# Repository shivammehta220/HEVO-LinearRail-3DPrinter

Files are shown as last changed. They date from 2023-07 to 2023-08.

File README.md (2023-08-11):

# HEVO 3D-Printer with Linear Rails
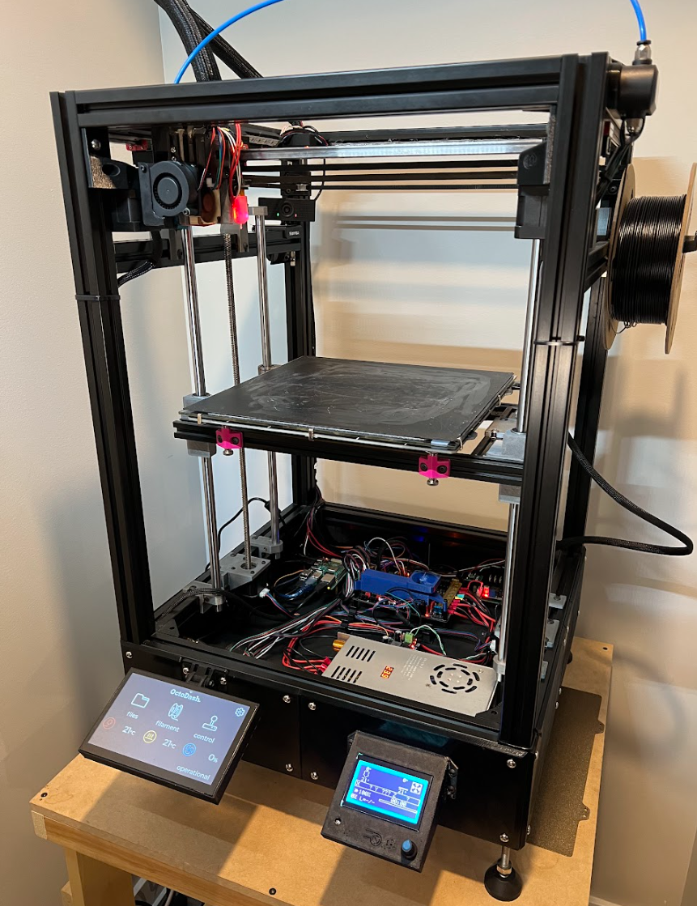
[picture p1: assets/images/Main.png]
Main

## About This Project
This project is an adaptation and build of the HyperCube Evolution (HEVO) project by SCOTT_3D. The objective was to construct a modified version of the HEVO printer with an increased height to achieve a larger build volume in the Z-axis. Additionally, the project aimed to incorporate a compartment for electronics and upgrade the original linear rods to MGN Linear rails.

The repository contains CAD files, documentation, STLs, BOMs, and Marlin files related to this project.

### Quick Links
1. [Electronics](/Electronics/README.md)
2. [Frame](/Design/README.md)
3. [Linear Rail Design](/Design/README.md)
4. [Octoprint](/Octoprint/README.md)

## [Electronics](/Electronics/README.md)
The electronics used in this project differ from the original design. They are all securely mounted using standoffs in the lower compartment of the frame. For the mainboard, the BIGTREETECH SKR PRO V1.1 Control Board with TMC2209 drivers was selected due to its ample room for expandability and future upgrades. The board is running Marlin 2.0, and the customized fork can be [found here](https://github.com/shivammehta220/Marlin/tree/HEVO).

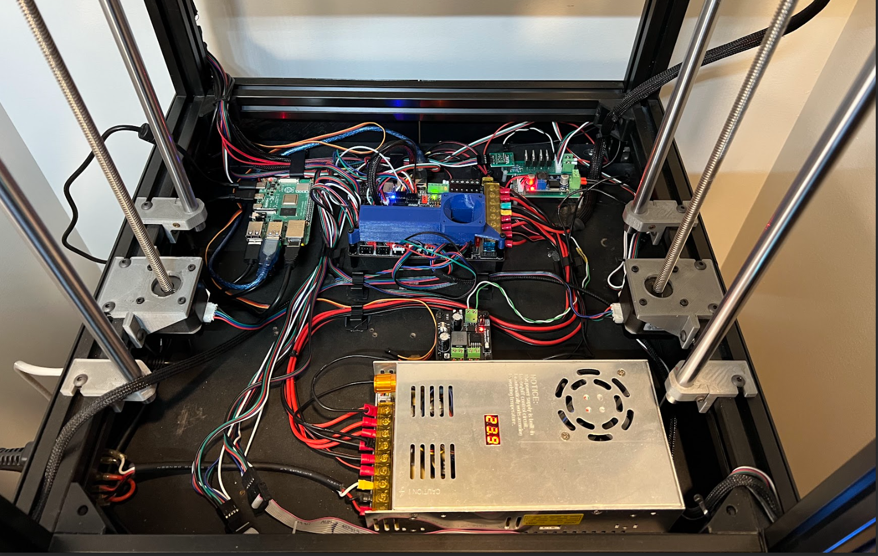
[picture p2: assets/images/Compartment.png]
Compartment


## [Frame](/Design/README.md)
The printer's frame was purchased and laser-cut from MISUMI, with overall dimensions of 440x450x700 mm. The frame is designed to provide stability and support for the printer components. The original build volume of SCOTT_3D's design is 300x300x300 mm, but it has been upgraded to 300x300x450 mm, with an additional 200 mm of extrusion in the lower section for housing the electronics. All printed components are made using PETG filament. The STLs and CAD files for all the components used, as well as the Hypercube configurator for the build layout, can be found in the Design folder of this repository.

## [Linear Rail Design](/Design/README.md)
To enhance the printer's performance, the linear rod rails used in the original design were replaced with linear rails. This upgrade was implemented using a project found at [https://www.thingiverse.com/thing:2839395]. Additionally, a custom bracket was designed to mount the Trianglelab BMG extruder + V6 Hotend. The CAD files for these upgrades are available in the Design folder of this repository.

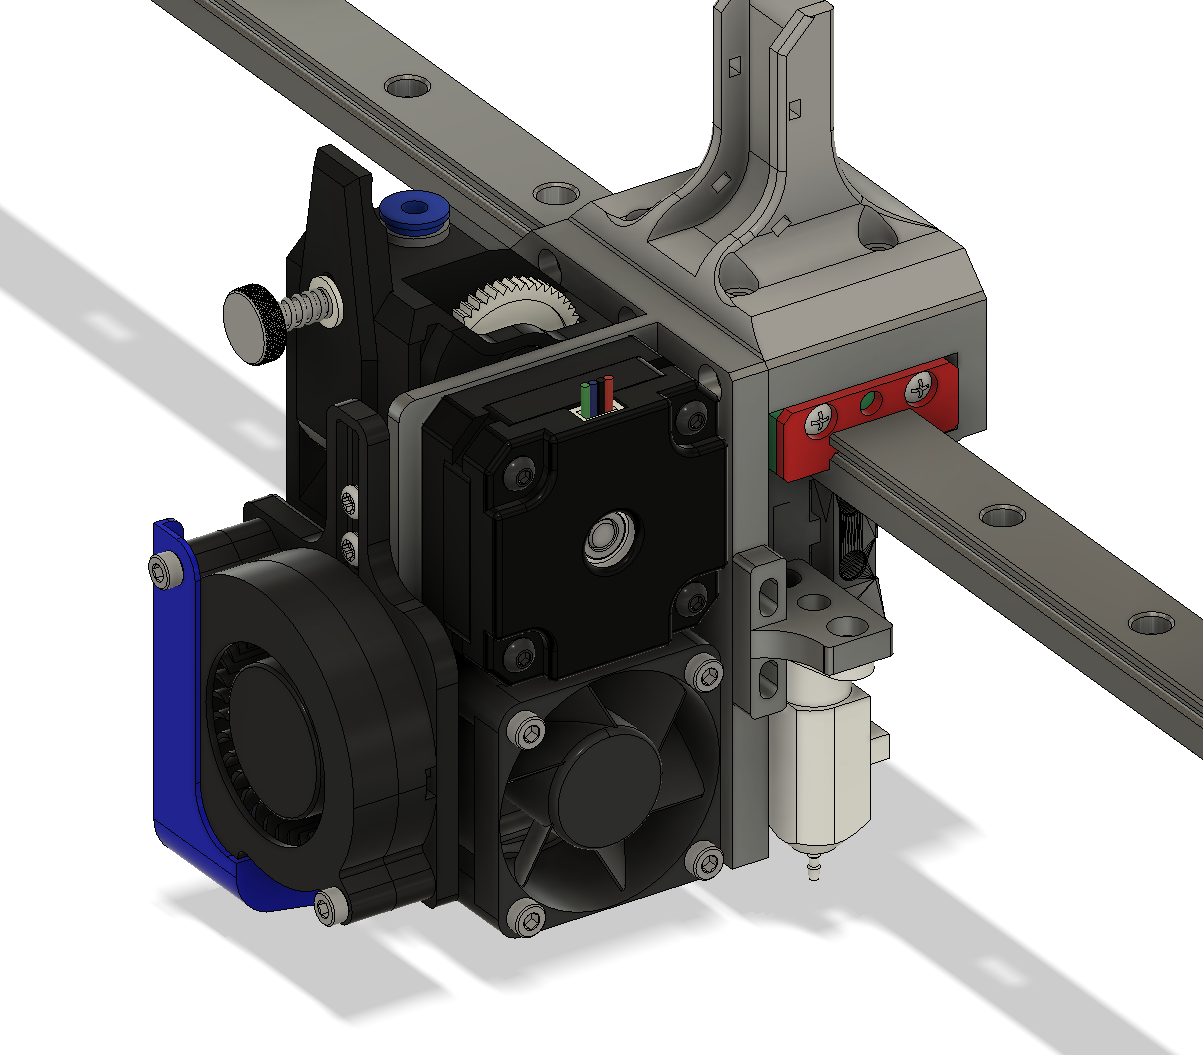
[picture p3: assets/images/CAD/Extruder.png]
Extruder


## [Octoprint](/Octoprint/README.md)
OctoPrint, a web interface for controlling and monitoring the printer remotely, is hosted on a Raspberry Pi 4. To complement the web interface, a 7-inch touch screen LCD is paired with the Pi to access the files. All plugins and settings for OctoPrint can be found in the OctoPrint folder of this repository, along with their corresponding links and documentations.

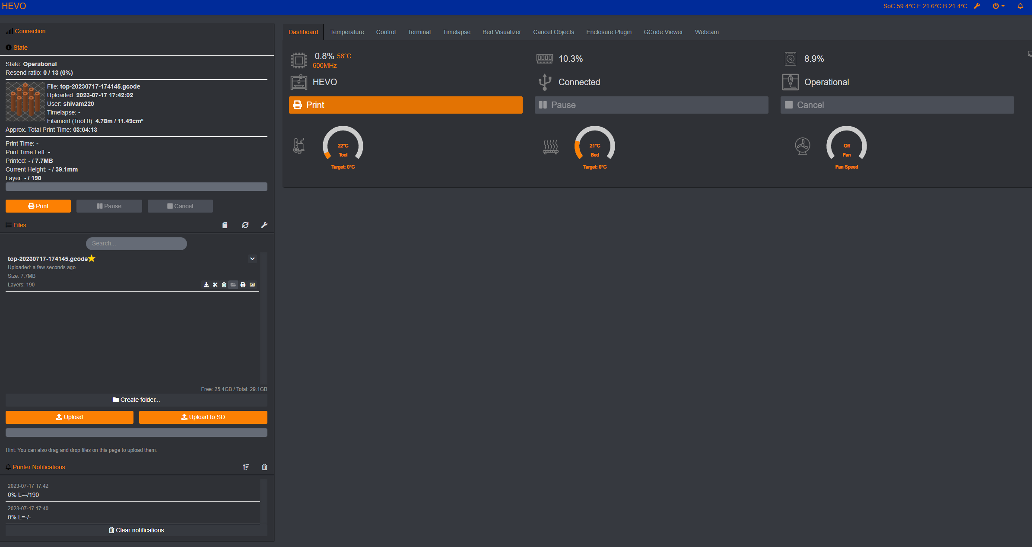
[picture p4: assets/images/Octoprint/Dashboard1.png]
Dashboard1


## Acknowledgements
This project is based on and adapted from the HyperCube Evolution project by SCOTT_3D. I would like to express my gratitude to SCOTT_3D for providing the inspiration and foundation for this project, as well as all the remixes that contributed to making it possible.

## License
The design files and documentation in this repository are licensed under MIT LICENSE. Please review the license file for more information.

Feel free to explore the repository and utilize the resources provided to build and customize your own version of the printer. If you have any questions or suggestions, please don't hesitate to reach out. Happy printing!

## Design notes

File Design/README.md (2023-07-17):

# Design
Before building the HEVO, a CAD model of the printer was created using Autodesk Fusion 360. This step was instrumental in ensuring accurate frame dimensions and assisting in the design of upgrades.

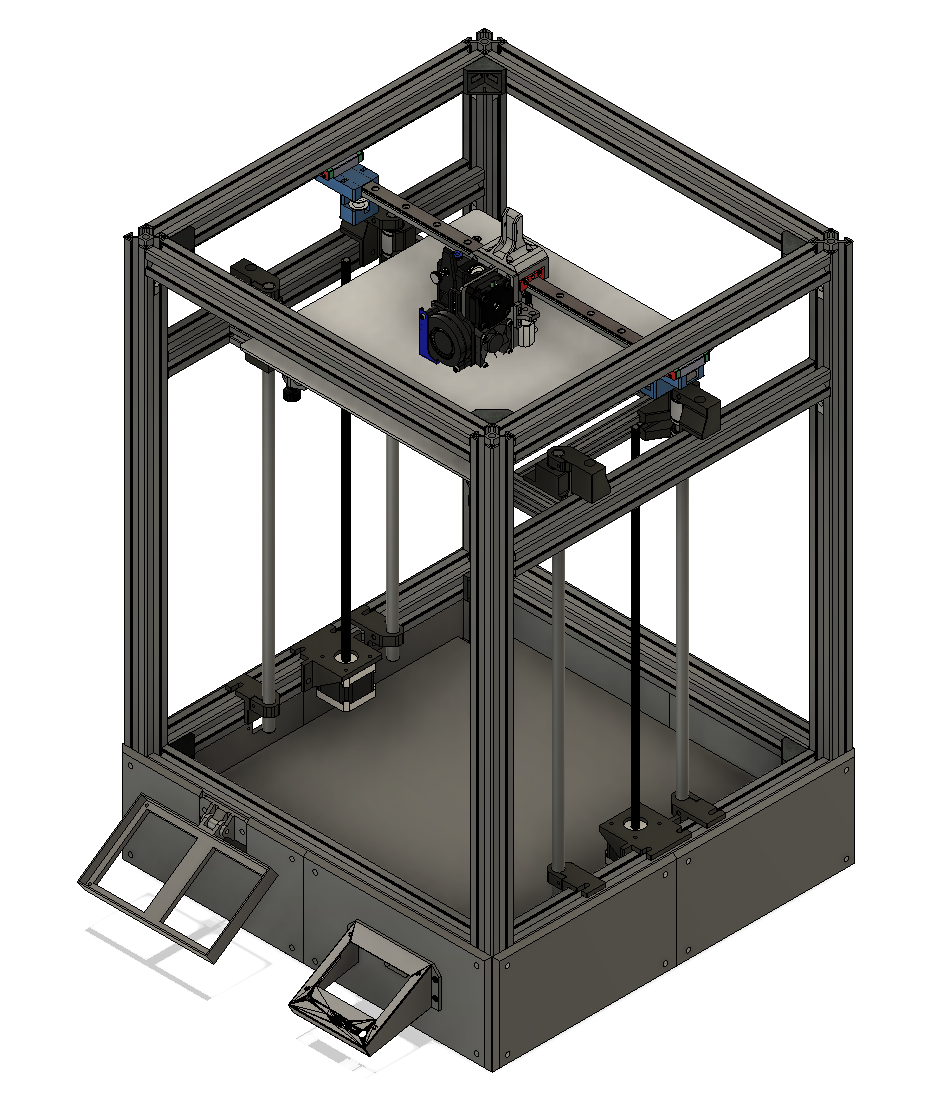
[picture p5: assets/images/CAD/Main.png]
CAD Main


## Extrusion
Instead of manually cutting the 3030 extrusion, which can introduce dimensional errors and lead to an uneven frame, I opted to have the individual extrusions laser-cut by MISUMI. The cost was reasonable, and the peace of mind in achieving a squared frame made it well worth it. The hardware for the frame and components were sourced from various online retailers and are all listed in the Bill of Materials (BOM) sheet.

| Extrusion (mm) | Type | Quantity |
| --- | --- | --- |
| 420 | 3030 Black Alu profiles | 6 |
| 410 | 3030 Black Alu profiles | 8 |
| 700 | 3030 Black Alu profiles | 4 |
| 415 | 2020 Black Alu profiles | 2 |
| 235 | 2020 Black Alu profiles | 2 |

## Linear Rail
To enhance the printer's performance, the original linear rod rails were upgraded to linear rails. This improvement was achieved by utilizing a project found at [https://www.thingiverse.com/thing:2839395]. Additionally, a custom bracket was designed to mount the Trianglelab BMG extruder + V6 Hotend.

Extruder

## CAD and STL
The repository provides the complete assembly CAD, including the frame design and any custom-designed components. Additionally, STL files for all the printed parts are included and organized in folders. Various components and features in the design were sourced from online platforms such as Thingiverse.

### 3030 LED by alexkainzinger 
>[Thingiverse Link](https://www.thingiverse.com/thing:3542857)

### Spool Holder by kuhnikuehnast 
> [Thingiverse Link](https://www.thingiverse.com/thing:3155344)

### Runout Sensor 3030 Mount by @scramsby_94717 
> [Printables Link](https://www.printables.com/model/110622-bigtreetech-smart-filament-sensor-3030-mount)

### RepRap Display by jmdunlap01
> [Thingiverse Link](https://www.thingiverse.com/thing:4787976)

### Bed Bracket by EagleB3
> [Thingiverse Link](https://www.thingiverse.com/thing:3656358)

### 3030 Cable Ties by bkahan
> [Thingiverse Link](https://www.thingiverse.com/thing:4384503)

### BIGTREETECH SKR PRO Cooling Tunnel by raabi91 
> [Thingiverse Link](https://www.thingiverse.com/thing:3747006)

These resources were instrumental in enhancing the functionality and usability of the HEVO printer design.

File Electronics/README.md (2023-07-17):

# Electronics
In this section, you can find the manuals and repositories related to the electronics used in the project. The complete list of electronics can be found in the BOM Excel sheet, but here are some of the main components:

| Component |
| ------------- |
| BIGTREETECH SKR PRO V1.1 Control Board  | 
| Trianglelab BMG extruder  | 
| Trianglelab V6 Hotend  | 
| 300x300 Magnetic Heated Bed  | 
| BLTOUCH Auto Bed Leveling Sensor | 
| 2 × NEMA17 0.9 Degree Stepper Motor - 40mm  | 
| BIGTREETECH Smart Filament Sensor Break Detection Module BTT SFS V1.0 Monitor | 
| 2 × NEMA17 Stepper Motor With Attached Lead Screw- 40mm  | 

## Electronics Compartment
The electronics compartment houses all the printer's electronics. It is enclosed with printed side panels and features cutouts for the power outlet, Ethernet, and both the RepRap display and the display for OctoPrint.

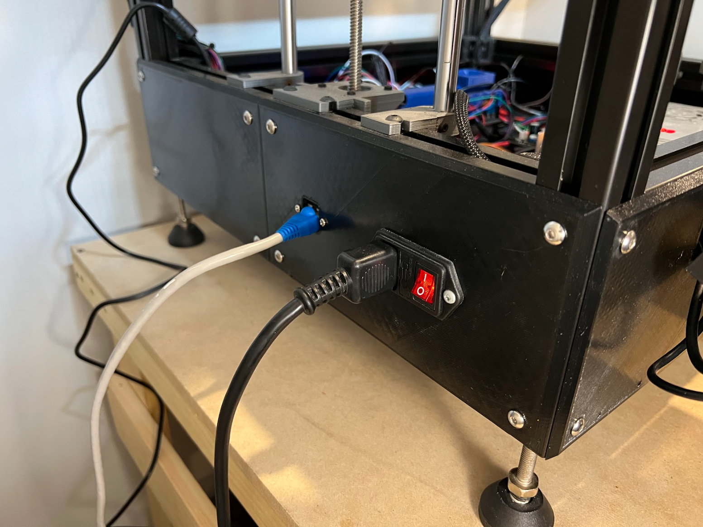
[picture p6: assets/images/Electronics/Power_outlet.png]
Power_outlet

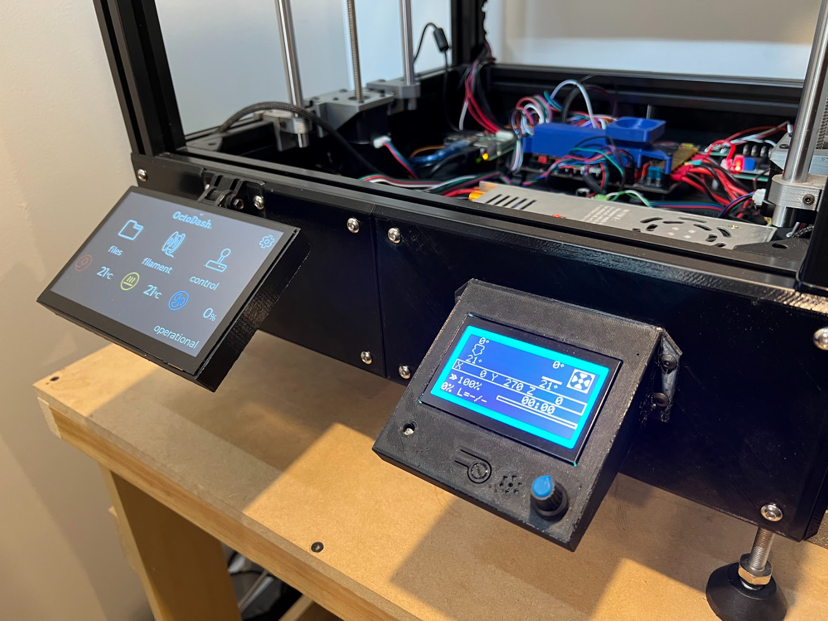
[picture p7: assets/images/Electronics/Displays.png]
Displays


## RGBW LED, 12V Regulator and Controller
To provide visualization of the print bed during prints and indicate the print status, RGBW LEDs are mounted on the 3030 extrusion frame. The LED strips themselves cannot be controlled by the SKR PRO V1.1 Control Board directly, so a basic MOSFET control circuit is used to turn the LEDs on and off. Additionally, since the power supply unit (PSU) operates at 24V, a 12V regulator is added to power the LEDs and other accessories (fans).

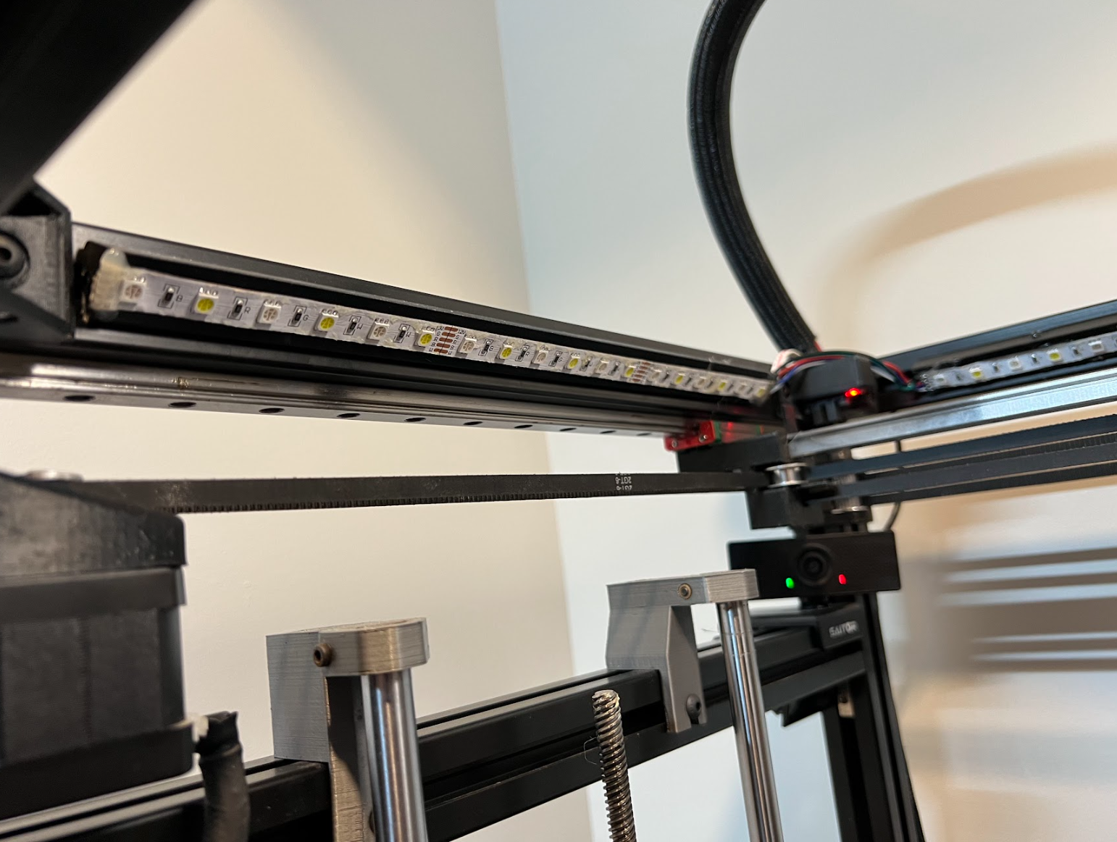
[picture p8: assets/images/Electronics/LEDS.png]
LEDS

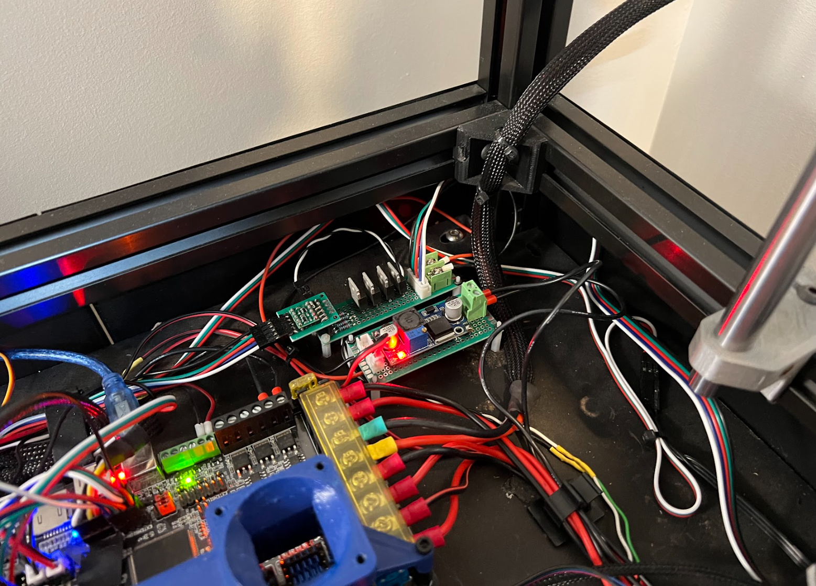
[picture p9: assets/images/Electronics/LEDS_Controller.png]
LEDS_Controller


The LEDs are connected to unused pins on the SKR PRO V1.1 Control Board, and the corresponding lines in the Marlin firmware are enabled to support LED control.
```
/**
 * RGB LED / LED Strip Control
 *
 * Enable support for an RGB LED connected to 5V digital pins, or
 * an RGB Strip connected to MOSFETs controlled by digital pins.
 *
 * Adds the M150 command to set the LED (or LED strip) color.
 * If pins are PWM capable (e.g., 4, 5, 6, 11) then a range of
 * luminance values can be set from 0 to 255.
 * For NeoPixel LED an overall brightness parameter is also available.
 *
 * *** CAUTION ***
 *  LED Strips require a MOSFET Chip between PWM lines and LEDs,
 *  as the Arduino cannot handle the current the LEDs will require.
 *  Failure to follow this precaution can destroy your Arduino!
 *  NOTE: A separate 5V power supply is required! The NeoPixel LED needs
 *  more current than the Arduino 5V linear regulator can produce.
 * *** CAUTION ***
 *
 * LED Type. Enable only one of the following two options.
 */
//#define RGB_LED
#define RGBW_LED

#if EITHER(RGB_LED, RGBW_LED)
  #define RGB_LED_R_PIN PD0
  #define RGB_LED_G_PIN PD2
  #define RGB_LED_B_PIN PD5
  #define RGB_LED_W_PIN PE0
#endif
```
## Smart Filament Sensor
The BIGTREETECH Smart Filament Sensor is not your typical mechanical or optical sensor. It is capable of detecting filament movement, allowing it to prevent false positives in case of filament breakage.

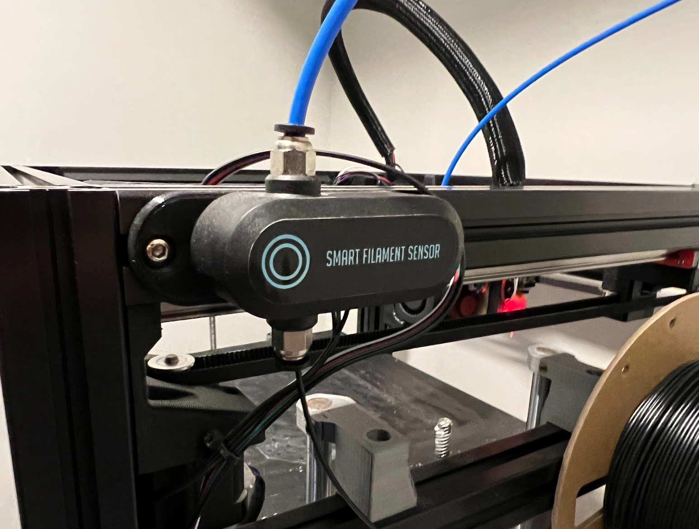
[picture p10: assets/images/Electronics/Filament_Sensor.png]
Filament_Sensor


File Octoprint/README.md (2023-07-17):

# Octoprint
OctoPrint is a web interface for remotely controlling and monitoring the printer, and in this project, it is hosted on a Raspberry Pi 4. The Raspberry Pi can be equipped with various accessories, which can be accessed through the web interface, allowing for convenient control and monitoring of the printer. Here are some of the plugins used in this build:

| Plugin | Link |
| --- | --- |
| OctoPrint-BLTouch | [Link](https://plugins.octoprint.org/plugins/BLTouch/) |
| Bed Visualizer |  [Link](https://plugins.octoprint.org/plugins/bedlevelvisualizer/) |
| OctoPrint-Cancelobject |  [Link](https://plugins.octoprint.org/plugins/cancelobject/) |
| OctoPrint-Dashboard | [Link](https://plugins.octoprint.org/plugins/dashboard/) |
| DisplayLayerProgress |  [Link](https://plugins.octoprint.org/plugins/DisplayLayerProgress/) |
| OctoPrint-FloatingNavbar |  [Link](https://plugins.octoprint.org/plugins/floatingnavbar/) |
| OctoPrint-NavbarTemp | [Link](https://plugins.octoprint.org/plugins/navbartemp/) |
| OctoPrint-OctoDashCompanion |  [Link](https://plugins.octoprint.org/plugins/octodashcompanion/) |
| OctoPrint-PrintTimeGenius |  [Link](https://plugins.octoprint.org/plugins/PrintTimeGenius/) |
| OctoPrint-PrusaSlicerThumbnails | [Link](https://plugins.octoprint.org/plugins/prusaslicerthumbnails/) |
| OctoPrint-Themeify |  [Link](https://plugins.octoprint.org/plugins/themeify/) |

## Dashboard

Dashboard1
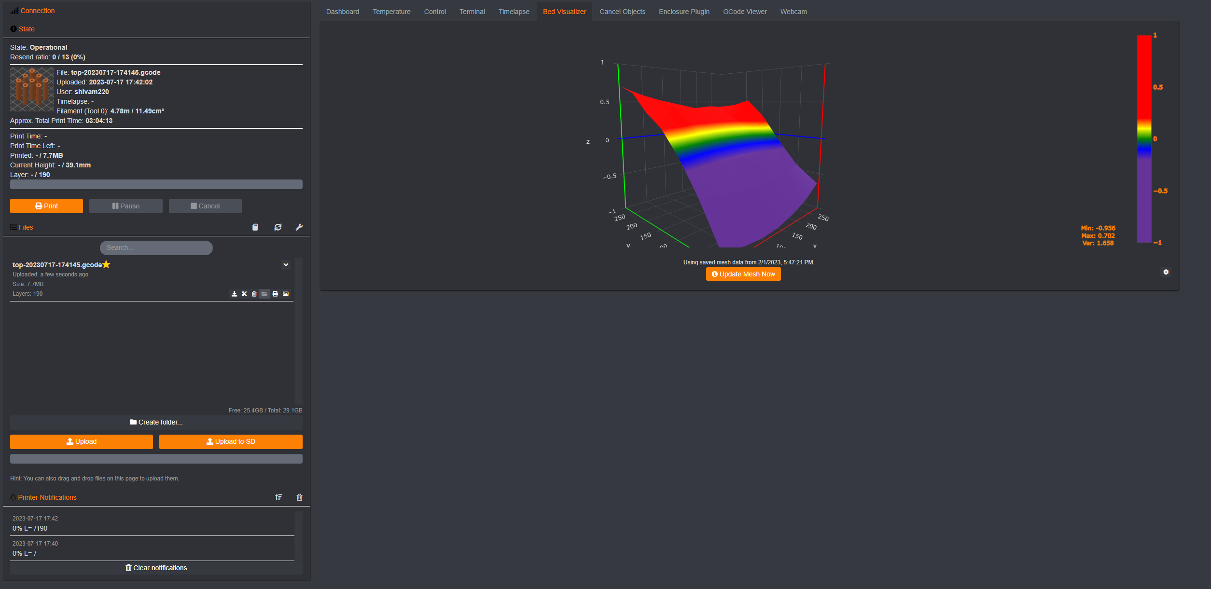
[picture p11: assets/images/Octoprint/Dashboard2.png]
Dashboard2

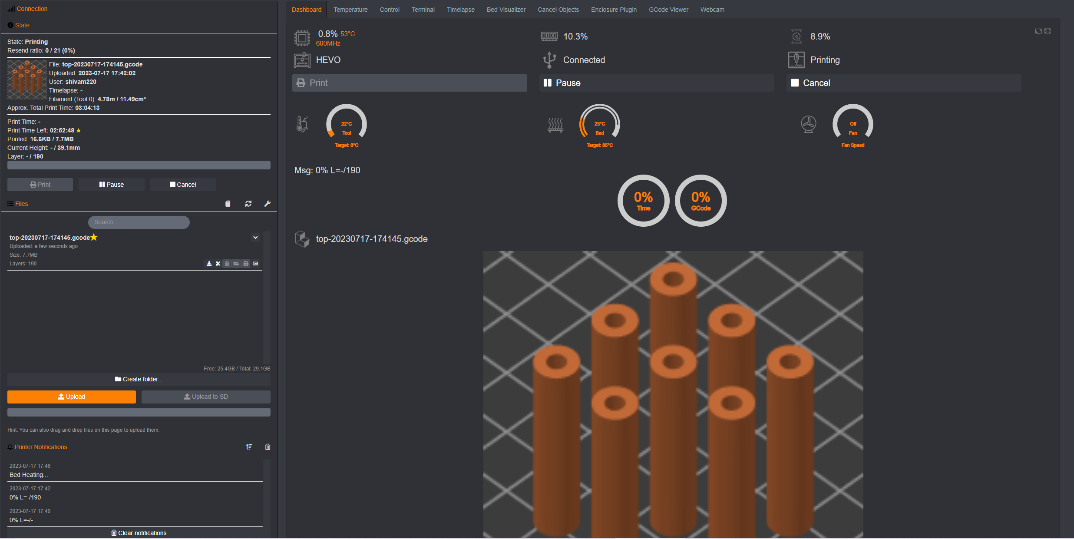
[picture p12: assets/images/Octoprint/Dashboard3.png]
Dashboard3


## Display
The OctoDash plugin is utilized to provide a simplified interface for OctoPrint, making it easier to access and manage print files directly at the printer once they have been uploaded.

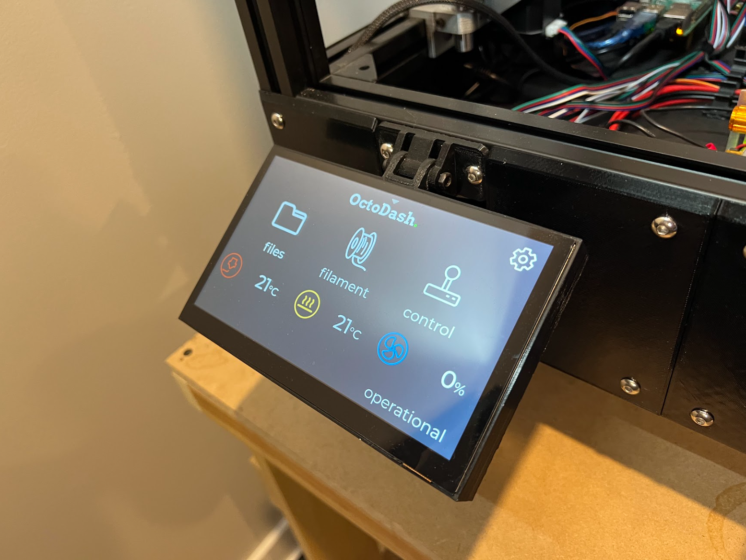
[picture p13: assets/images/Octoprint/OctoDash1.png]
OctoDash1

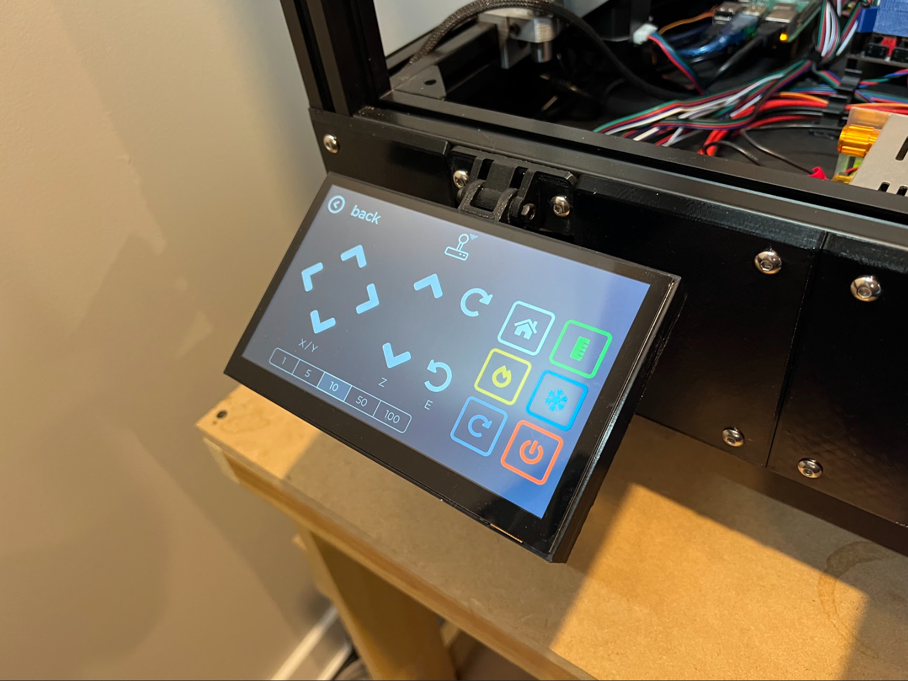
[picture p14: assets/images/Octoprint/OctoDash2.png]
OctoDash2


## Webcam

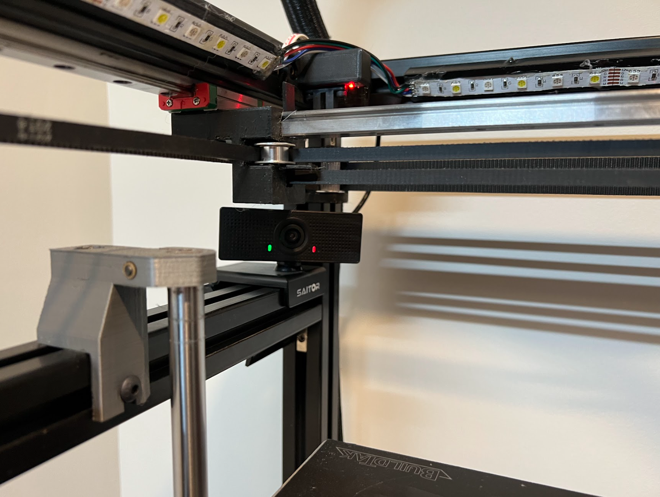
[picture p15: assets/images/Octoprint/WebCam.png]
WebCam

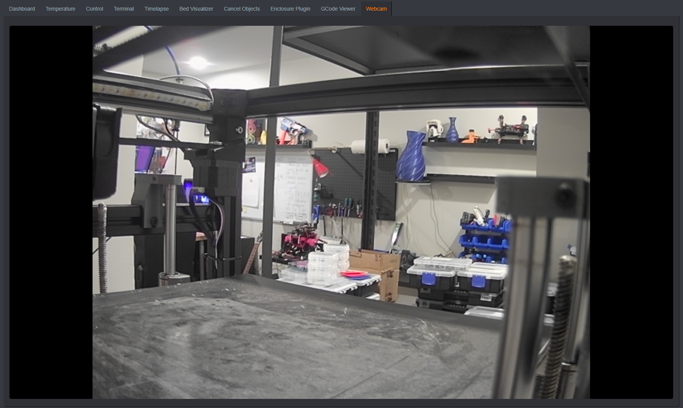
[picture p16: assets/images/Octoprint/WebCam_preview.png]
WebCam_preview


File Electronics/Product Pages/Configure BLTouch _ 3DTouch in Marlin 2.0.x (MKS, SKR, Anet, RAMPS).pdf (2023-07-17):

Reviews (https://3dwork.io/en/review/) | Printing guides (https://3dwork.io/en/printing-guides/) | Electronics (https://3dwork.io/en/electronics/) | DIY Projects (https://3dwork.io/en/projects/)

## Tools

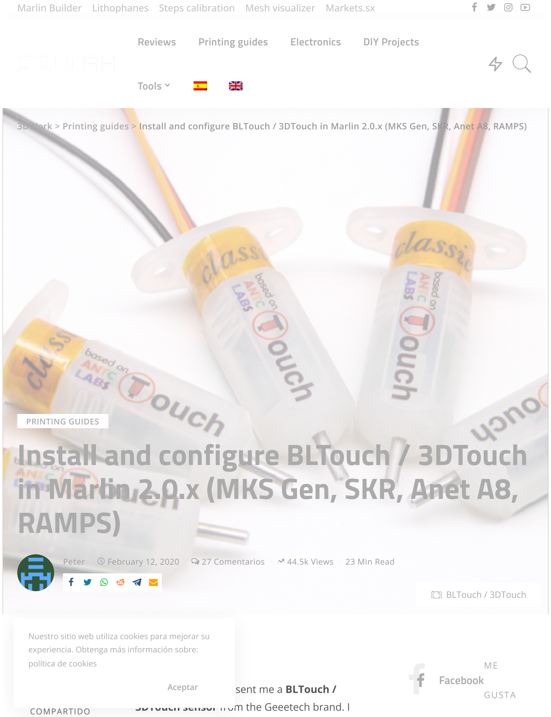
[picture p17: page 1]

Marlin Builder (https://3dwork.io/marlin) Lithophanes (https://3dwork.io/litofania) Steps calibration (https://docs.google.com/spreadsheets/d/11upBCJkprqZASurKaLHrECy6sttyQK6xYzohi2u45dE/edit#gid=0) Mesh visualizer (https://mkdev.co.uk/mesh-visualizer/) Markets.sx b (https://www.facebook.com/3DWork.Spain) d (https://twitter.com/3dwork_io) 4 (https://www.instagram.com/3dwork.io) (https://www.youtube.com/@3dwork_io159)

0

COMPARTIDO

Recently a colleague sent me a BLTouch / 3DTouch sensor from the Geeetech brand. I

## Facebook

ME

GUSTA (https://facebook.com/3DWork.Spain)

# Install and configure BLTouch / 3DTouch

in Marlin 2.0.x (MKS Gen, SKR, Anet A8,

# RAMPS)

Peter (https://3dwork.io/en/author/peter/) | S February 12, 2020 | V 27 Comentarios | R 44.5k Views (https://3dwork.io/en/configure-bltouch-in-marlin/) | 23 Min Read

b (https://www.facebook.com/sharer.php?u=https%3A%2F%2F3dwork.io%2Fen%2Fconfigure-bltouch-in-marlin%2F) d (https://twitter.com/intent/tweet?via=3dwork_io) Z (https://web.whatsapp.com/send) E (https://www.reddit.com/submit) (https://t.me/share/) P

PRINTING GUIDES (https://3dwork.io/en/categoria/printing-guides/)

3DWork (https://3dwork.io/en/) > Printing guides (https://3dwork.io/en/categoria/printing-guides/) > Install and configure BLTouch / 3DTouch in Marlin 2.0.x (MKS Gen, SKR, Anet A8, RAMPS)

# bb (https://facebook.com/3DWork.Spain)

L BLTouch / 3DTouch

Nuestro sitio web utiliza cookies para mejorar su experiencia. Obtenga más información sobre:

política de cookies (https://3dwork.io/politica-de-cookies/)

Aceptar b (https://www.facebook.com/sharer.php?u=https%3A%2F%2F3dwork.io%2Fen%2Fconfigure-bltouch-in-marlin%2F) d (https://twitter.com/intent/tweet?via=3dwork_io)

Z (https://web.whatsapp.com/send) g (https://linkedin.com/shareArticle?mini=true)

- (https://t.me/share/) P

SIGUIENTE

## SKR GTR V1.0: Complete analysis and configuration with TMC22xx drivers and Sensorless (Marlin 2.0.x.x) (https://3dwork.io/en/skr-gtr-v1-0-analysis-and-configuration/)

usually use optical infrared sensors for my printers, but I wanted to try the BLTouch sensors since none had fallen yet by my hands. So I got down to work for Configure BLTouch with BabyStepping in the last (https://3dwork.io/en/configure-bltouch-in-marlin) Marlin available today and satiate my curiosity.

I have always used leveling sensors on my machines, as leveling the four corners of the printing surface with a folio is definitely not my thing. Nor do I see it practical and much less precise, although at this point I surely disagree with some reader

I have to say that I tried quite a few inductive and capacitive sensors, I even opted for the original PINDA 2 , which is very comfortable to install since is one of the few that actually powers 5V and gives quite a bit of precision. But it didn’t convince me either. In each and every one of them a common denominator, the detection distance varies depending on the metal and even the temperature of the bed.

It’s something I don’t like at all. It doesn’t give me any sense of precision, since what I’m looking for is an immutable (or at least minimal) measurement. Having a component that according to the conditions of use works differently has no meaning whatsoever. I don’t want to calibrate that distance again if I change the filament from PLA to ABS, it’s a

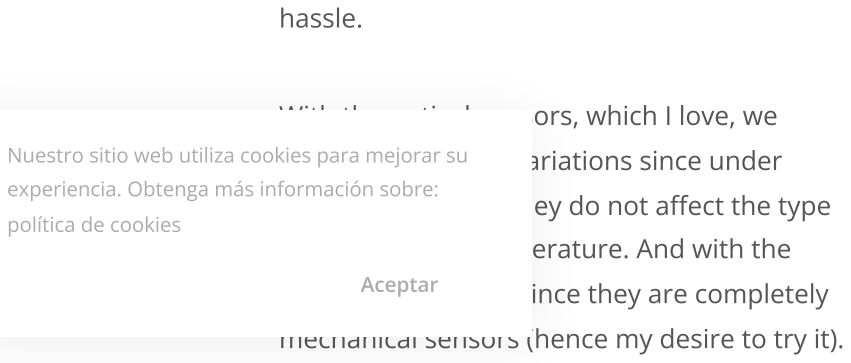
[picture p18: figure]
hassle.; experiencia. Obtenga más información sobre:; política de cookies

With the optical sensors, which I love, we forget about these variations since under normal conditions they do not affect the type of metal or the temperature. And with the BLTouch the same, since they are completely mechanical sensors (hence my desire to try it).

## Twitter SEGUIR (https://twitter.com/3dwork_io)

## 816 SeguidoresSEGU (https://instagram.com/3dwork.io)

## 2.6k MembersÚNET (https://t.me/The3DWorkChannel)

LATEST POSTS

## Elegoo Neptune 3 Pro / Plus / Max : which one to choose? (https://3dwork.io/en/elegoo-neptune-3-pro-plus-max-which-one-to-choose/)

S
May 23,
2023

## Raspberr y Pad 5: more than just a screen (https://3dwork.io/en/raspberry-pad-5-algo-mas-que-una-simple-pantalla/)

S
February 3,
2023

## BIQU Hurakan (https://3dwork.io/en/biqu-hurakan/)

S
January 13,
2023

## Warming up for Black Friday

2022:

## Offers from

Elegoo,

## Anycubic, (https://3dwork.io/en/black-friday-2022/)

# d (https://twitter.com/3dwork_io) 4 (https://instagram.com/3dwork.io) - (https://t.me/The3DWorkChannel)

## d (https://twitter.com/3dwork_io)

## 4 (https://instagram.com/3dwork.io)

## - (https://t.me/The3DWorkChannel)

Nuestro sitio web utiliza cookies para mejorar su

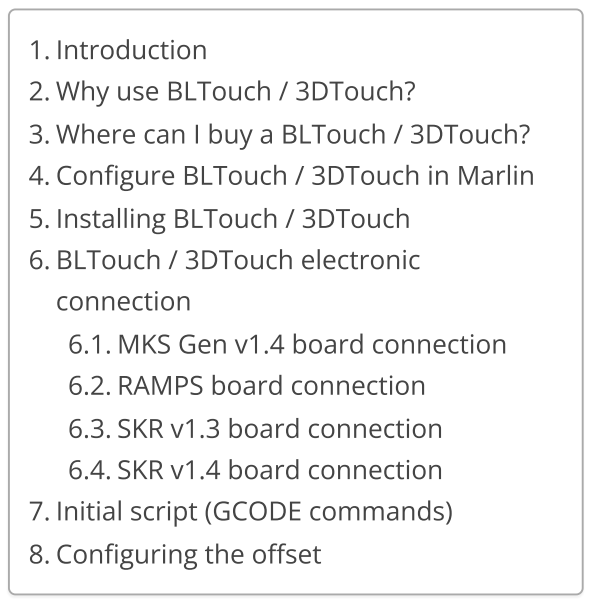
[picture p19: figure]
1. Introduction; 2. Why use BLTouch / 3DTouch?; 3. Where can I buy a BLTouch / 3DTouch?; 5. Installing BLTouch / 3DTouch; 6. BLTouch / 3DTouch electronic; connection; 6.1. MKS Gen v1.4 board connection; 6.2. RAMPS board connection; 6.3. SKR v1.3 board connection; 6.4. SKR v1.4 board connection; 7. Initial script (GCODE commands); 8. Configuring the offset

# Introduction

Before starting I have to confess that I do not have a commercial 3D printer as many of you may have ( Anet A8 , Ender3 or Artillery X1 for example). I had a commercial at the beginning (a completely disaster), so I decided to design and manufacture my own to my liking and needs.

However, you should not worry because when configuring the BLTouch sensor the options to be modified in the Marlin firmware will be exactly the same . The only thing that will vary will be the connections, but we will indicate some examples so that you do not have any problem in its corresponding section.

In this article we will only discuss the options to modify to support BLTouch / 3DTouch. If you need to completely configure Marlin do not hesitate to visit the Complete guide: (https://3dwork.io/configurar-marlin-2-0-x-desde-cero/)

Voxelab,

## etc. (https://3dwork.io/en/black-friday-2022/)

S
November
23, 2022

## Anycubic Kobra Neo & Go

:

## Completi ng the Kobra series (https://3dwork.io/en/anycubic-kobra-neo-go/)

S
November
22, 2022
4. Configure BLTouch / 3DTouch in Marlin

Nuestro sitio web utiliza cookies para mejorar su experiencia. Obtenga más información sobre:

política de cookies (https://3dwork.io/politica-de-cookies/)

Configure Marlin 2.0.3 from scratch and not die trying that you also have available on our (https://3dwork.io/configurar-marlin-2-0-x-desde-cero/) website.

# Why use BLTouch / 3DTouch?

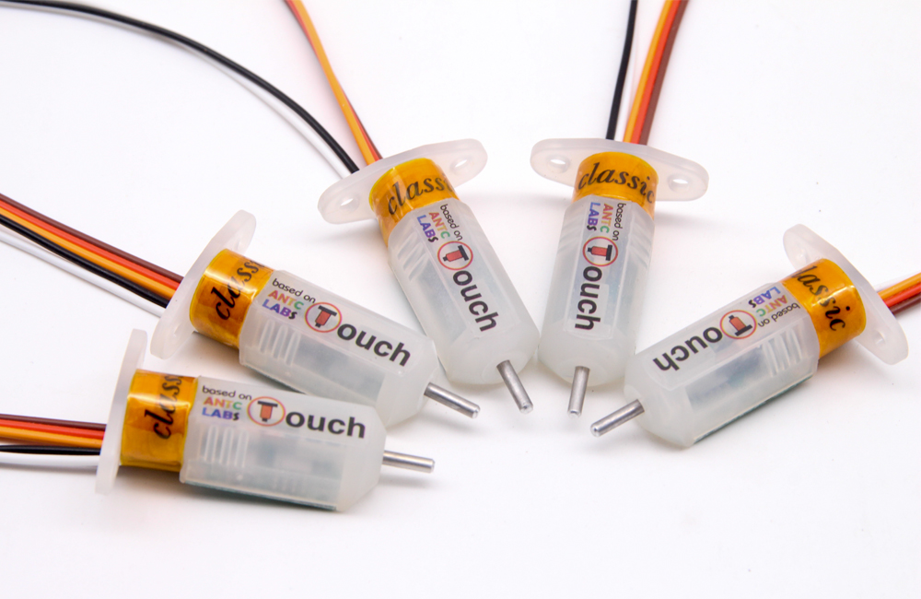
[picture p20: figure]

The main reason for me would be not having to be leveling 4 corners with a sheet of paper or making squares in bed. If we make the leveling of the printing surface in the 4 corners, when you are leveling one another it is unbalanced. In the end, so that everything is square, you end up making several passes, especially if you are a precision maniac.

So the question is extremely simple. Why not install a leveling sensor to level at a single central point in the bed (SAFE_HOMING), and let Marlin generate the mesh of points and worry about the rest? That’s what Marlin is for, to make life easier for us.

For more reasons, you can install capacitive or inductive sensors, but these types of sensors vary depending on the temperature of the bed and the metal. The higher the temperature, the lower the detection range. So you can not

Nuestro sitio web utiliza cookies para mejorar su experiencia. Obtenga más información sobre:

política de cookies (https://3dwork.io/politica-de-cookies/)

leave a fixed value for PLA and another for ABS.

In addition, on aluminum the detection range of capacitive and conductive sensors is considerably reduced with respect to using steel or iron. Another negative point since if you use glass you will be very fair and in any failure your nozzle will go through the glass with the consequent risk of breakage.

BLTouch / 3DTouch sensors are mechanical, so they are not affected by heat, humidity or the type of material on your printing surface.

Furthermore, the connection of the BLTouch / 3DTouch sensors to the boards is relatively simple and you do not need to carry out any electronic modification as it happens in other sensors. Some Chinese sensors indicate operating ranges from 6-36v, nothing is further from reality. If you feed them at minimum values they don’t work, so you have to feed them at 12v.

The problem comes when you have to send the signal (S) to your electronic board, if you don’t regulate that voltage (with additional electronics) you can burn the port as it happened to me in my MKS Gen v1.4. The result was that the Z- was completely unusable for me having inserted 12v. in a 5v input. It is not a major problem, you can change within the Marlin firmware and indicate that for Z- we are going to use the Z+, but you have to make unnecessary modifications.

Nuestro sitio web utiliza cookies para mejorar su experiencia. Obtenga más información sobre:

política de cookies (https://3dwork.io/politica-de-cookies/)

# Where can I buy a BLTouch / 3DTouch?

You can buy this type of sensor in any online store, since they are very common in the world of 3D printing. Below I leave you two affiliate links to Amazon and Banggood. Of course you can buy them wherever you want, there are dozens of pages.

If you decide to acquire it through these links, it is my duty to tell you that a small commission will go to the 3DWork.io project and we will be eternally grateful to you. In this way we can continue writing 3D printing guides and articles on interest. Or alternatively, you can follow us on our social networks.

BLTouch Original (Antclabs)

3DTouch

Bigtreetech 3DTouch v3.0

Creality 3D BLTouch v2

Or if you wish, you can use our component search engine Markets.sx, where you can compare prices in different Marketplaces (Amazon, Aliexpress, Banggood, etc.) with a

N | single search and very easily. uestro sitio web utiliza cookies para mejorar su

experiencia. Obtenga más información sobre:

política de cookies (https://3dwork.io/politica-de-cookies/)

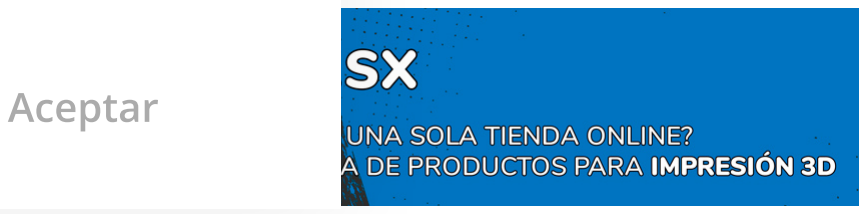
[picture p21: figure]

# Configure BLTouch / 3DTouch in Marlin

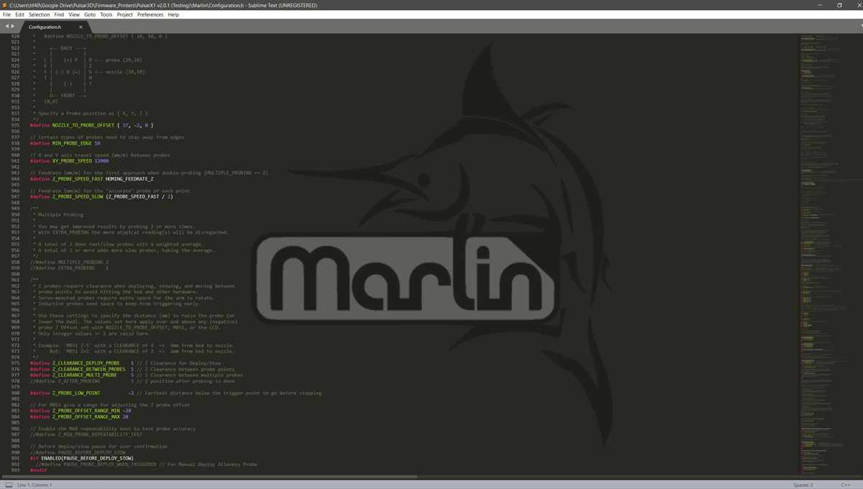
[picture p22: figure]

Well, let’s start configuring our Marlin firmware to support BLTouch / 3DTouch sensors. As I explained in the previous article of Configure Marlin 2.0.3 from scratch, to activate the (https://3dwork.io/configurar-marlin-2-0-x-desde-cero) options you simply have to uncomment them. This is done by removing the two bars in front of each #define, this way the compiler can make use of them and add them to the final firmware.

We will start the configuration by editing the file Configuration.h with your favorite text editor (mine is Sublime). (https://www.sublimetext.com/) Once you have edited it, we are going to indicate to our dear Marlin that our 3D printer has a limit switch (sensor) on the Z axis. We will proceed to uncomment the USE_ZMIN_PLUG options.

### // Specify here all the endstop conne // Almost all printers will be using

// extra connectors. | Leave undefined

### #define USE_XMIN_PLUG

Nuestro sitio web utiliza cookies para mejorar su experiencia. Obtenga más información sobre: | | #define USE_YMIN_PLUG
| | #define USE_ZMIN_PLUG
| | //#define USE_XMAX_PLUG
| | //#define USE_YMAX_PLUG
| | //#define USE_ZMAX_PLUG

política de cookies (https://3dwork.io/politica-de-cookies/)

Now we uncomment the option Z_MIN_PROBE_USES_Z_MIN_ENDSTOP_PIN.

And in this other line of the code we are going to indicate that our installed sensor is a BLTouch / 3DTouch, which for Marlin come to be the same.

If we use a self-leveling sensor (either BLTouch or any other), we must indicate to Marlin the position of the sensor with respect to our print nozzle. This will necessarily be separated and we will define it as coordinates and in millimeters.

My leveling BLTouch is 37mm to the right of the nozzle, and 2mm behind it, so I would put the following settings. You must measure these values to enter on your printer (do not use mine).

/**

### * Z_MIN_PROBE_USES_Z_MIN_ENDSTOP_PIN

*

### * Enable this option for a probe con

*/

### #define Z_MIN_PROBE_USES_Z_MIN_ENDSTO

/**

### * The BLTouch probe uses a Hall effe

*/

### #define BLTOUCH

Nuestro sitio web utiliza cookies para mejorar su experiencia. Obtenga más información sobre:

política de cookies (https://3dwork.io/politica-de-cookies/)

Now we must uncomment the
AUTO_BED_LEVELING_BILINEAR function and then the RESTORE_LEVELING_AFTER_G28 function, so that they remain active in our firmware.

/**

### * Z Probe to nozzle (X,Y) offset, re

*

### * In the following example the X and

*

### * #define NOZZLE_TO_PROBE_OFFSET {

*
* | +-- BACK ---+
* | | | | |
* | L | | (+) P | R &amp;amp;lt;--
* | E | | | | I
* | F | (-) N (+) | G &amp;amp;lt;--
* | T | | | | H
* | | | (-) | | T
* | | | | |
* | O-- FRONT --+
* | (0,0)
*

### * Specify a Probe position as { X, Y

*/
#define NOZZLE_TO_PROBE_OFFSET { 37,

/**

### * Choose one of the options below to * and behavior of G29 will change de

*

### * If using a Probe for Z Homing, en

*

### * - AUTO_BED_LEVELING_3POINT

* | Probe 3 arbitrary points on the
* | You specify the XY coordinates o
* | The result is a single tilted pl
*
| | * - AUTO_BED_LEVELING_LINEAR
* Probe several points in a grid.
* You specify the | rectangle and th
Nuestro sitio web utiliza cookies para mejorar su experiencia. Obtenga más información sobre: política de cookies (https://3dwork.io/politica-de-cookies/) | | * The result is a | single tilted pl
| | *
| | * - AUTO_BED_LEVELING_BILINEAR
| | * Probe several points in a grid.
| | * You specify the | rectangle and th
| * The result is a | | mesh, best for l
| *
| * - AUTO_BED_LEVELING_UBL (Unified B

Once the type of self-leveling that we want Marlin to carry out is configured, we will indicate with the GRID_MAX_POINTS parameters the number of probes (or tests) to be carried out. I usually make 9 checkpoints before each print, you can expand or reduce it, that is up to you.

And since I always like to do HOMING in the center of the bed for safety, I activate the Z_SAFE_HOMING option.

* A comprehensive | bed leveling sys

### * of other systems. UBL also inclu

| * Validation and Mesh Editing syst
*

### * - MESH_BED_LEVELING

* | Probe a grid manually
* | The result is a mesh, suitable f
* | For machines without a probe, Me
* | leveling in steps so you can man
* | With an LCD controller the proce
*/

### //#define AUTO_BED_LEVELING_3POINT //#define AUTO_BED_LEVELING_LINEAR #define AUTO_BED_LEVELING_BILINEAR //#define AUTO_BED_LEVELING_UBL //#define MESH_BED_LEVELING

/**

### * Normally G28 leaves leveling disab * this option to have G28 restore th

*/

### #define RESTORE_LEVELING_AFTER_G28

### // Set the number of grid points per #define GRID_MAX_POINTS_X 3 #define GRID_MAX_POINTS_Y GRID_MAX_PO

### #define Z_SAFE_HOMING

Nuestro sitio web utiliza cookies para mejorar su experiencia. Obtenga más información sobre:

política de cookies (https://3dwork.io/politica-de-cookies/)

Now we will save the Configuration.h file and edit a new file called Configuration_adv.h . The difference compared to Configuration.h is that it offers us more detailed customization options, and experimental or in development functions.

In my printer I use a leveling function available in Marlin 2 called BABYSTEPPING. This function allows me to calibrate the height of my leveling sensor in the center of the bed once with a sheet of paper.

Later, the printer will perform 9 probe points automatically at the beginning of each print. This way I won’t have to go corner by corner unnecessarily to calibrate my bed. By default it is deactivated, so we will activate the BABYSTEPPING option, as I show you below:

### if ENABLED(Z_SAFE_HOMING) #define Z_SAFE_HOMING_X_POINT ((X_BED

| #define Z_SAFE_HOMING_Y_POINT ((Y_BED

### #endif

### define BABYSTEPPING #if ENABLED(BABYSTEPPING) //#define BABYSTEP_WITHOUT_HOMING //#define BABYSTEP_XY // Also enable #define BABYSTEP_INVERT_Z false // Ch #define BABYSTEP_MULTIPLICATOR_Z 20 / #define BABYSTEP_MULTIPLICATOR_XY 1

| | #define DOUBLECLICK_FOR_Z_BABYSTEPPIN

### if ENABLED(DOUBLECLICK_FOR_Z_BABYSTE #define DOUBLECLICK_MAX_INTERVAL 1250

// Note: Extra | time | may be added to m

### define BABYSTEP_ALWAYS_AVAILABLE // //#define MOVE_Z_WHEN_IDLE // Jump to #if ENABLED(MOVE_Z_WHEN_IDLE) #define MOVE_Z_IDLE_MULTIPLICATOR 1 / #endif #endif

Nuestro sitio web utiliza cookies para mejorar su experiencia. Obtenga más información sobre:

política de cookies (https://3dwork.io/politica-de-cookies/)

Well, these would be the basic options to configure your BLTouch. Of course, you can configure much more parameters such as limits, polls, travel speeds, etc. But for starters it is more than enough.

# Installing BLTouch / 3DTouch

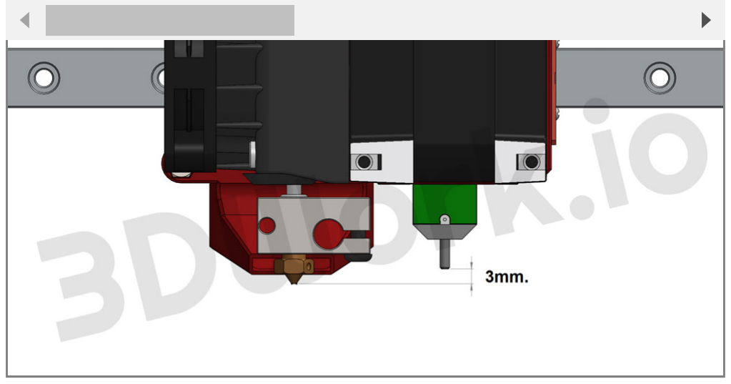
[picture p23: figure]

Regardless of where it is located with respect to the X and Y axes, which are the ones you must configure in Marlin, you have to position the BLTouch / 3DTouch sensor at a certain distance in height from your nozzle.

It is logically has to be within its range of action. When the probe is retracted, it must be above the nozzle (otherwise we will have problems). And when it is extended, it must lower several millimeters below the nozzle to be able to act.

### //#define BABYSTEP_DISPLAY_TOTAL // D

### define BABYSTEP_ZPROBE_OFFSET // Com #if ENABLED(BABYSTEP_ZPROBE_OFFSET) //#define BABYSTEP_HOTEND_Z_OFFSET // #define BABYSTEP_ZPROBE_GFX_OVERLAY / #endif #endif

Nuestro sitio web utiliza cookies para mejorar su experiencia. Obtenga más información sobre:

política de cookies (https://3dwork.io/politica-de-cookies/)

The recommended is 2mm. As I have seen in some places, but it was a little short after some tests and I decided to set it to 2.5mm. that works for me correctly. Of course, this distance is at your absolute choice, it is only a guideline value.

# BLTouch / 3DTouch electronic connection

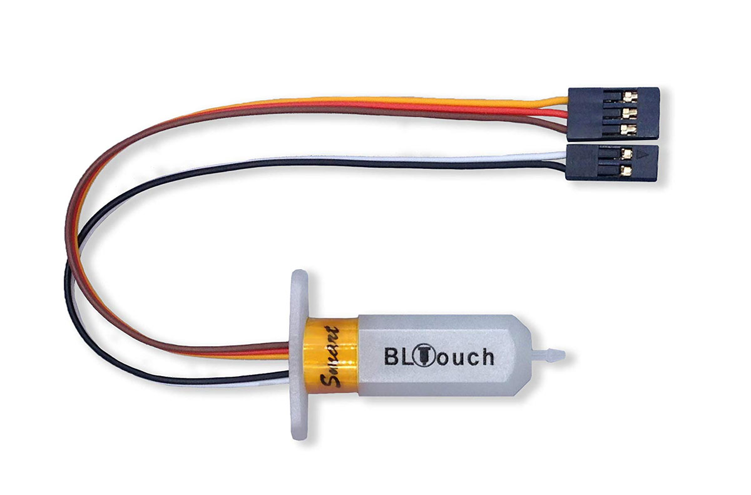
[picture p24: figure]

As you can see in this image, the BLTouch / 3DTouch leveling sensors have two connection cables. One with three pins and the other with two pins, which will be the ones we will need to connect to our electronics.

In my case, I use MKS Gen v1.4, so the connection couldn’t be easier (just like in RAMPS). Below I leave you 2 images so you can see where the BLTouch would be connected on my board, and on a RAMPS board, much more common than the one I own.

# MKS Gen v1.4 board connection

Nuestro sitio web utiliza cookies para mejorar su experiencia. Obtenga más información sobre:

política de cookies (https://3dwork.io/politica-de-cookies/)

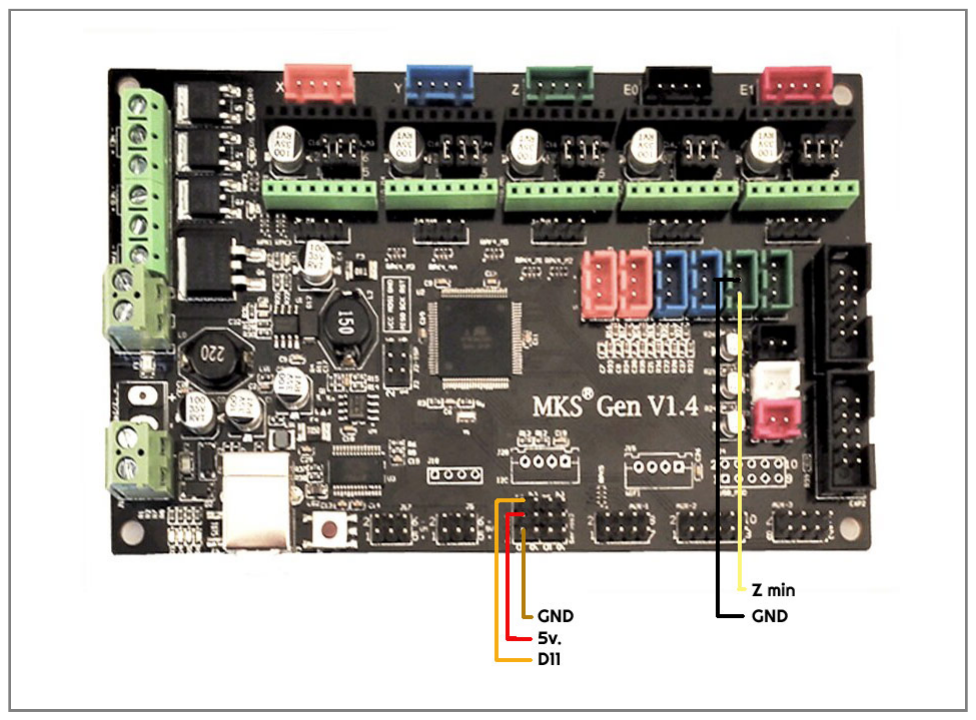
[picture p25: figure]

Very easy as you have been able to check, click on those 2 sites and that’s it. When you turn on the printer you will see that the sensor does a little checking (unfolds and retracts the probe).

# RAMPS board connection

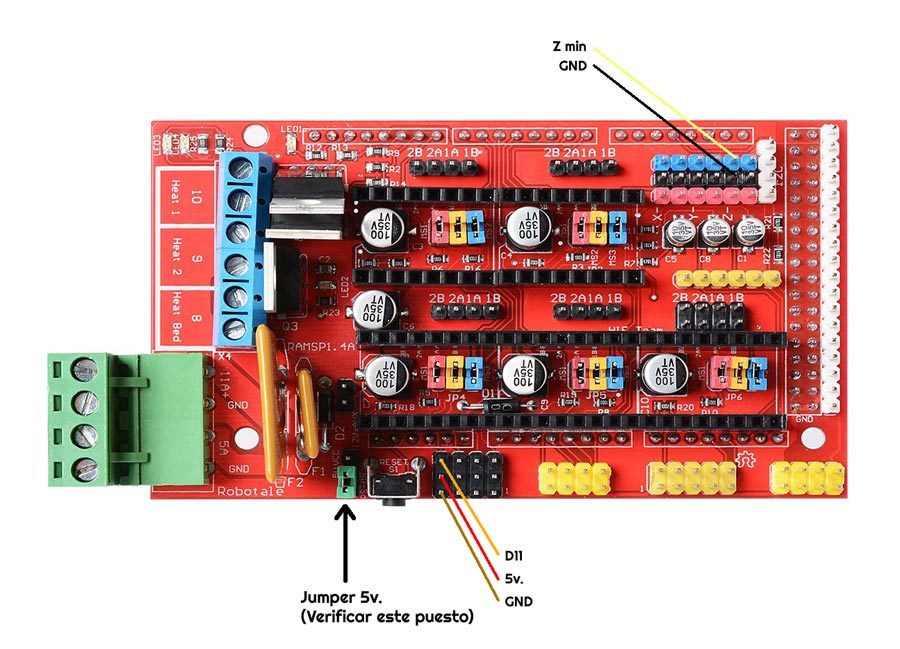
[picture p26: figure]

This connection is similar, but you must make sure that you have the jumper activated, so we will make sure that the level sensor reaches the 5v. necessary (very important).

# SKR v1.3 board connection

Nuestro sitio web utiliza cookies para mejorar su experiencia. Obtenga más información sobre:

política de cookies (https://3dwork.io/politica-de-cookies/)

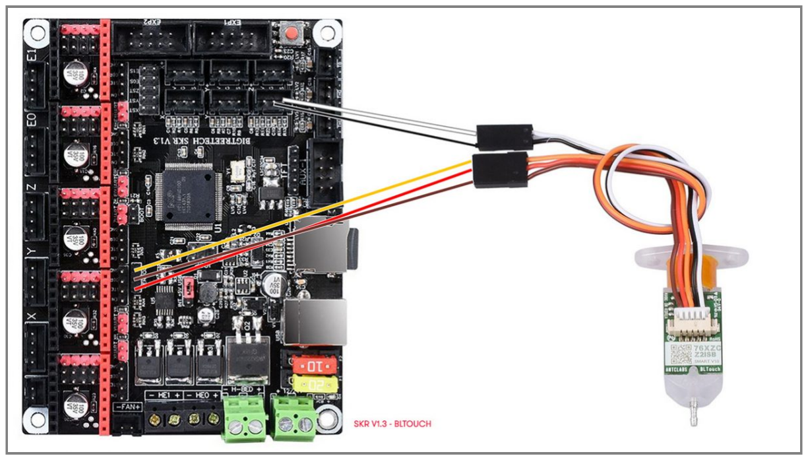
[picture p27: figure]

# SKR v1.4 board connection

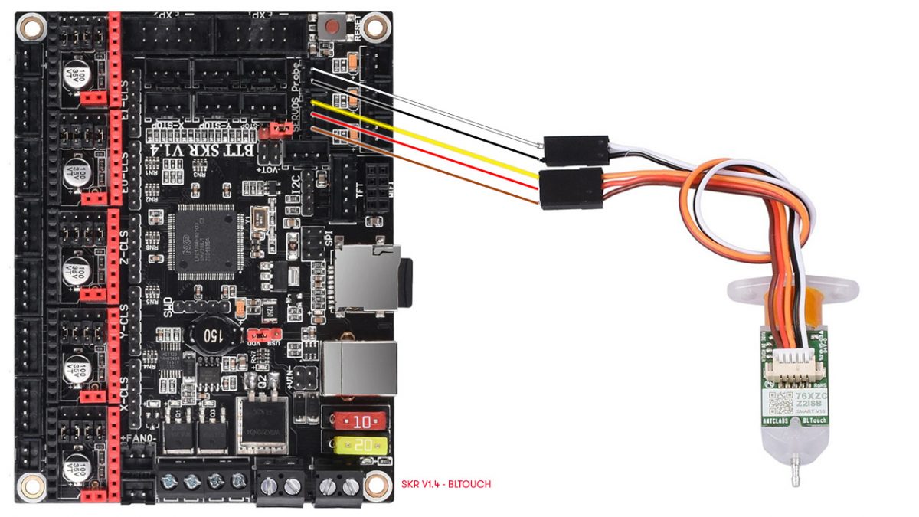
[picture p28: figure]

Just one important thing. In the case that connecting the 2 wires to the Probe connector the sensor not works, try to connect to the ZMin connector. Depending of the firmware version of your Marlin, in some cases it gives issues, but if you connect to ZMin it will work perfectly.

# Initial script (GCODE commands)

You will need to add the self-leveling function at the beginning of each print. This is done very easily by configuring yourself in your favorite Slicer (Repetier, Simplify3D, Cura, etc.). It is simply adding the G29 command to level your head before each impression.

Nuestro sitio web utiliza cookies para mejorar su experiencia. Obtenga más información sobre:

política de cookies (https://3dwork.io/politica-de-cookies/)

I leave you an example of my startup script on each print:

# Configuring the offset

To finish, and having activated BabyStepping you will have your own menu called Offset. You can access it before the printing process and during (yes, you read me correctly) the printing process by pressing the button twice on your display.

In this way, and in real time, you can adjust the offset while you are making the first printing perimeters, and leave a perfect fit. To me this has saved me the odd impression, the truth is that it is quite useful.

G28 | ; Make HOME on all axes
G29 | ; Auto-leveling command

### G1 Z5 F5000 ; Nozzle up

M75 | ; Launch timer

Nuestro sitio web utiliza cookies para mejorar su experiencia. Obtenga más información sobre:

política de cookies (https://3dwork.io/politica-de-cookies/)

Once you have made the offset settings, don’t forget to save the value in memory. You should have an option called Record to EEPROM , as long as you have supported it in your Marlin. If you can’t find it, you can alternatively run the command M500 (Save settings). This will store all the current settings in your EEPROM permanently.

If you have read the complete article, I congratulate you. It would not be surprising if he had left me something in the pipeline, if so, do not hesitate to notify me in the comments at the end of the article Install and configure BLTouch / 3DTouch in Marlin 2.0.x (MKS Gen, SKR, Anet A8, RAMPS).

Finally remind you, as always, that you can find us on our Telegram channel full of maniacs by 3D printing at next link, (https://t.me/joinchat/FzEj0ETGzUJVtc9DD1kgZQ) or on our social networks (don’t forget to follow us if you like the web).

If you wish, you can find other interesting articles in 3DWork at the following links:

DyzeXtruder Pro: Analysis of a high-; performance extruder for professional; environments; experiencia. Obtenga más información sobre:; política de cookies

Complete guide SKR v1.4 / v1.4 Turbo with

TMC2209 Sensorless drivers and Display TFT35

Nuestro sitio web utiliza cookies para mejorar su

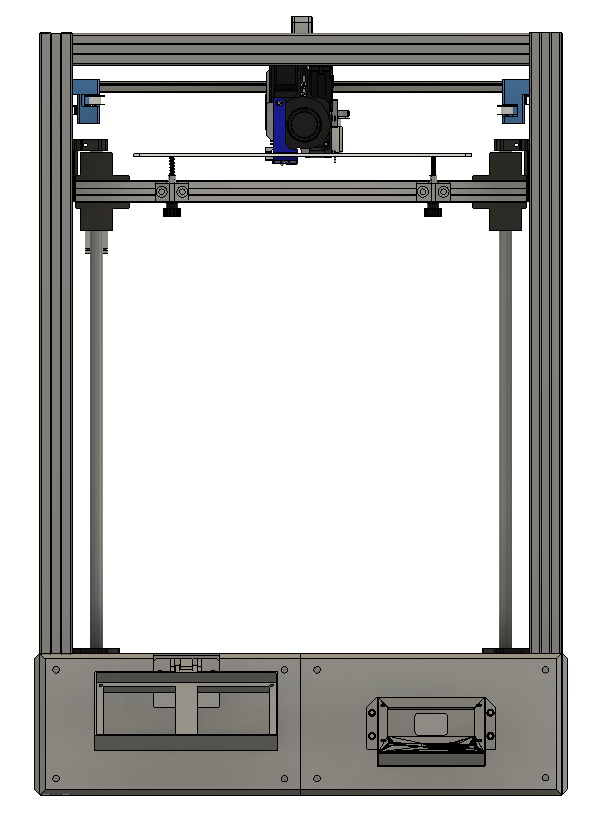
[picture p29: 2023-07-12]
assets/images/CAD/Front.png

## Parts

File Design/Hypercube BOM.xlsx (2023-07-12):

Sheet: Frame
Part | Quantity | Price | Store | Link
420mm 3030 Black Al profiles | 6 | 34.26 | Misumi | https://us.misumi-ec.com/vona2/detail/110302686450/?HissuCode=HFSB6-3030-700
410mm 3030 Black Al profiles | 8 | 44.56 | Misumi | https://us.misumi-ec.com/vona2/detail/110302686450/?HissuCode=HFSB6-3030-700
700mm 3030 Black Al profiles | 4 | 38.08 | Misumi | https://us.misumi-ec.com/vona2/detail/110302686450/?HissuCode=HFSB6-3030-700
415mm 2020 Black Al profiles | 2 | 8.04 | Misumi | https://us.misumi-ec.com/vona2/detail/110302683830/?HissuCode=HFSB5-2020-235
235mm 2020 Black Al profiles | 2 | 5.8 | Misumi | https://us.misumi-ec.com/vona2/detail/110302683830/?HissuCode=HFSB5-2020-235
L type bracket for 3030 extrusion | 30 | 49.77 | Amazon
L type bracket for 2020 extrusion | 10 | 15 | Spool3D | https://spool3d.ca/l-hidden-corner-bracket-for-2020/
M5*10 Button Head Socket Bolts | 100 | 14.99 | Amazon | https://www.amazon.ca/gp/product/B07FF28LMD/ref=ppx_od_dt_b_asin_title_s01?ie=UTF8&psc=1
M6*10 Button Head Socket Bolts with 30-M6 Hummer nuts | 25 | 15.49 | Amazon | https://www.amazon.ca/gp/product/B0833WGQHB/ref=ppx_od_dt_b_asin_title_s01?ie=UTF8&psc=1
Black M3 Socket head screws | 1 | 20.99 | Amazon | https://www.amazon.ca/gp/product/B07JNF11VG/ref=ppx_od_dt_b_asin_title_s01?ie=UTF8&psc=1
M5 T Hammer Nuts for 3030 extrusion | 150 | 45 | Spool3D | https://spool3d.ca/m5-t-nut-hammer-head-nickel-plated/
M5 T Hammer Nuts for 2020 extrusion | 50 | 11.5 | Spool3D | https://spool3d.ca/m5-t-nut-hammer-head-nickel-plated/
M4 DIN7991 FLAT Socket Head Cap Screw - 45mm | 4 | 3 | Spool3D | https://spool3d.ca/m4-din7991-flat-socket-head-cap-screw-a2-stainless-steel/
Knurled Nut - M4 Thread | 4 | 6 | Spool3D | https://spool3d.ca/knurled-nut-m4-thread/
Blue Spring | 5 | 12.5 | Spool3D | https://spool3d.ca/blue-spring/
3mm dowel pins | 100 | 14 | Amazon | https://www.amazon.ca/gp/product/B07X8DZ8V6/ref=ppx_yo_dt_b_search_asin_title?ie=UTF8&psc=1
M3 5x5 Brass knurled insert | 100 | 10.99 | Amazon | https://www.amazon.ca/gp/product/B07VFCR8TY/ref=ppx_yo_dt_b_asin_title_o04_s01?ie=UTF8&psc=1
GT2 Timing Pulley (20 teeth) 3mm bore for 6mm belt | 3 | 1.41 | Aliexpress | https://www.aliexpress.com/item/32781681772.html?spm=a2g0s.9042311.0.0.2bc54c4dD2GDIF
GT2 Idler Pulley (20 teeth) 3mm bore | 10 | 10.93 | Aliexpress | https://www.aliexpress.com/item/32825019861.html?spm=a2g0s.9042311.0.0.2bc54c4dD2GDIF
GT2 Idler Pulley without teeth (20 teeth) 3mm bore | 5 | 4.43 | Aliexpress | https://www.aliexpress.com/item/32822906447.html?spm=a2g0s.9042311.0.0.2bc54c4dD2GDIF
5m Polyurethane GT2 6mm belt | 1 | 5.68 | Aliexpress | https://www.aliexpress.com/item/32822761985.html?spm=a2g0s.9042311.0.0.2bc54c4dD2GDIF

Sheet: Linear Rail
Part | Quantity | Price | Store | Link
MGN15H Linear Guide and Block - Rail Length: 500 mm | 1 | 38 | Spool3D | https://spool3d.ca/mgn15h-linear-guide-and-block/
MGN12H Linear Guide and Block - Rail Length: 450 mm | 2 | 68 | Spool3D | https://spool3d.ca/mgn12h-linear-guide-and-block/

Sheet: Electronics
Part | Quantity | Price | Store | Link
300x300 Magnetic Heated Bed | 1 | 67.8 | Aliexpress | https://www.aliexpress.com/item/33041249544.html?spm=a2g0s.9042311.0.0.2bc54c4dD2GDIF
NEMA17 0.9 Degree Stepper Motor - 40mm | 2 | 46 | Spool3D | https://spool3d.ca/nema17-0-9-degree-stepper-motor-40mm/
NEMA17 Stepper Motor With Attached Lead Screw- 450mm | 2 | 104 | Spool3D | https://spool3d.ca/nema17-stepper-motor-with-attached-lead-screw-40mm/
Trianglelab BMG extruder + V6 Hotend | 1 | 65.04 | Aliexpress | https://www.aliexpress.com/item/32922611810.html?spm=a2g0s.9042311.0.0.2bc54c4dD2GDIF
BL Touch | 1 | 18.56 | Aliexpress | https://www.aliexpress.com/item/32832887426.html?spm=a2g0s.9042311.0.0.2bc54c4dD2GDIF
PTFE Tubing | 1 | 3.98 | Aliexpress | https://www.aliexpress.com/item/32811240720.html?spm=a2g0s.9042311.0.0.2bc54c4dD2GDIF
V6 Nozzle | 1 | 2.94 | Aliexpress | https://www.aliexpress.com/item/32965509920.html?spm=a2g0s.9042311.0.0.2bc54c4dD2GDIF
24V 480W power supply | 1 | 42.69 | Amazon | https://www.amazon.ca/gp/product/B071DQPRR5/ref=ppx_od_dt_b_asin_title_s01?ie=UTF8&psc=1
Optical end stops | 6 | 4.73 | Aliexpress | https://www.aliexpress.com/item/32782429622.html?spm=a2g0s.9042311.0.0.2bc54c4dD2GDIF
3 in 1 Fuse Power switch AC power outlet | 1 | 6.4 | Aliexpress | https://www.aliexpress.com/item/32818103790.html
24V Centrifugal Fan - Ball Bearing - 50mm x 50mm | 1 | 8 | Spool3D | https://spool3d.ca/24v-centrifugal-fan-ball-bearing-50mm-x-50mm/
14 AWG Black and Red Silicon Wire 10ft | 1 | 13.31 | Amazon | https://www.amazon.ca/gp/product/B017TFR6SM/ref=ppx_od_dt_b_asin_title_s01?ie=UTF8&psc=1
22 AWG 6 color Silicon wire 8 meters | 1 | 22.99 | Amazon | https://www.amazon.ca/gp/product/B07G2JWYDW/ref=ppx_od_dt_b_asin_title_s01?ie=UTF8&psc=1
22 AWG Black and Red Wire 65 ft | 1 | 13.99 | Amazon | https://www.amazon.ca/gp/product/B074386X3V/ref=ppx_od_dt_b_asin_title_s00?ie=UTF8&psc=1
Dupont Connector kit | 1 | 8.16 | Aliexpress | https://www.aliexpress.com/item/32839071531.html?spm=a2g0s.9042311.0.0.2bc54c4dD2GDIF
SM2.54 kit | 1 | 6.6 | Aliexpress | https://www.aliexpress.com/item/32864346321.html?spm=a2g0s.9042311.0.0.2bc54c4dD2GDIF
Xh2.54 kit | 1 | 8.04 | Aliexpress | https://www.aliexpress.com/item/32699295522.html?spm=a2g0s.9042311.0.0.2bc54c4dD2GDIF
1/2 inch Sleeving 25 FT | 1 | 11.99 | Amazon | https://www.amazon.ca/gp/product/B071ZV6MZ2/ref=ppx_od_dt_b_asin_title_s00?ie=UTF8&psc=1
1/4 inch Sleeving 25ft | 1 | 9.99 | Amazon | https://www.amazon.ca/gp/product/B071JH14WZ/ref=ppx_od_dt_b_asin_title_s00?ie=UTF8&psc=1
BIGTREETECH SKR PRO V1.1 Control Board w/ TMC2209 | 1 | 119 | Spool3D | https://spool3d.ca/bigtreetech-skr-pro-v1-1-control-board/
Power Cable | 1 | 10 | Spool3D | https://spool3d.ca/10-amp-power-cable/
5050 LED Strip RGBW, Waterproof | 1 | 12.59 | Aliexpress | https://www.aliexpress.com/item/1599651146.html
IRLZ44N MOSFET | 5 | 10 | Aliexpress | https://www.aliexpress.com/item/1005001279833153.html
BIGTREETECH Smart Filament Sensor Break Detection Module BTT SFS V1.0 Monitor | 1 | 29 | Spool3D | https://spool3d.ca/bigtreetech-smart-filament-sensor-break-detection-module-btt-sfs-v1-0-monitor/
BuildTak Flexplate System | 1 | 159 | Spool3D | https://spool3d.ca/buildtak-flexplate-system/
Borosilicate Heat Bed Glass for 3D Printers - Square Sizes | 1 | 38 | Spool3D | https://spool3d.ca/borosilicate-heat-bed-glass-for-3d-printers-square-sizes/
E3D Swiss Clip | 8 | 10 | Spool3D | https://spool3d.ca/e3d-swiss-clip/
Heat Bed Insulation - High Temperature Ceramic Fibre Cotton | 1 | 9 | Spool3D | https://spool3d.ca/heat-bed-insulation-high-temperature-ceramic-fibre-cotton/
12864 LCD Smart Controller Display | 1 | 29 | Spool3D | https://spool3d.ca/12864-lcd-smart-controller-display/
Raspberry Pi 4 Model B | 1 | 140 | Amazon | https://www.amazon.ca/Raspberry-Model-2019-Quad-Bluetooth/dp/B07TC2BK1X
7 inch LCD 1024x600 Resolution Capacitive Touch Screen IPS | 1 | 80 | Amazon | https://www.amazon.ca/gp/product/B08RHXP9J4/ref=ppx_yo_dt_b_search_asin_title?ie=UTF8&psc=1
NexiGo 1080P Webcam | 1 | 24 | Amazon | https://www.amazon.ca/dp/B08BHX7GYY?s=pc&sp_csd=d2lkZ2V0TmFtZT1zcF9kZXRhaWw
Noctua NF-A4x10 FLX, | 1 | 18.85 | Amazon | https://www.amazon.ca/gp/product/B009NQLT0M/ref=ppx_yo_dt_b_search_asin_title?ie=UTF8&psc=1

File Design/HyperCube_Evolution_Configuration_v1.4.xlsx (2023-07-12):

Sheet: Sheet1
Calculations - do not change
Parameter name | Equation | Unit | Design parameters
extrusion_size | 30 | mm
frame_width | 480 | mm | X Axis
frame_depth | 470 | mm | x_carriage_travel_min | 300
frame_height | 600 | mm | x_carriage_depth_rear | 14.5 | y offset from CL of x guides to rear of x carriage
platform_width | 328 | mm | x_carriage_width | 55
platform_depth | 328 | mm | x_carriage_nozzle_offset | 45.75 | y offset from CL of x guides to CL of nozzle
hole_spacing_width | 325 | mm | x_guide_spacing | 45
hole_spacing_depth | 325 | mm | x_guide_length | 450
bed_extrusion_size | 20 | mm | x_min_bed_offset | 30 |  | for dual z axis, the minimum distance between the z linear guide CL and the edge of the heated bed
bed_frame_width | 415 | mm |  |  |  |  |  | 325
bed_frame_depth | 295 | mm
bed_cl_y_offset | 216.25 | mm | Y Axis
T8_screw_length | 250 | mm | y_carriage_travel_min | 300
bracket_size | 15 | mm | y_min_offset | 31.5 | y min offset from inside of frame = width of XY motor mount
 |  |  | y_max_offset | 12 | y max offset from inside of frame = thickness of XY idler
 |  |  | y_carriage_depth | 58 | 2 x length of LM10UU bearing
 |  |  | y_carriage_width | 45 | from CL of Y axis guide to inside edge
 |  |  | y_guide_min_spacing | 445 | length of x axis guides
Build Platform | Equation | Unit | y_guide_length | 410
X width | 328 | mm
Y depth | 328 | mm | Z Axis
X spacing | 325 | mm | z_bed_travel_req | 400 |  | Note: lead screw should be this length + nut length
Y spacing | 325 | mm | z_nozzle_offset | 113.7 |  | Distance from top of frame to underside of nozzle
Bracket size | 15 | mm | z_bed_height | 68 |  | Distance from bottom of Z bearing holder to print surface
 |  |  | z_min_offset | 17 |  | Distance from bottom of frame to underside of Z bearing holder in Z Max position (bottom)
 |  |  | z_guide_diameter | 12 |  | Z linear guide diameter
 |  |  | z_guide_y_offset | 22 | CL offset from inside of frame
 |  |  | z_guide_length | 500
 |  |  |  |  |  | Single Z | Double Z
 |  |  | min_frame_width | 475 |  | 475 | 462
 |  |  | min_frame_depth | 463 |  | 463 | 388
 |  |  | min_frame_height | 598.7
 |  |  | min_bed_frame_width |  |  | 295 | 415
 |  |  | min_bed_frame_depth |  |  | 400 | 295
 |  |  | bed_mounting_width | 0 |  | 325 | 325
 |  |  | bed_mounting_depth | 0 |  | 325 | 325
 |  |  |  | 0

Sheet: Configuration
HyperCube
Evolution |  |  |  |  |  |  | Configurator | v1.4 | Build platform data
 |  |  |  |  |  |  |  |  |  | Dimensions |  | Mounting Holes
 |  |  |  |  |  |  |  |  | Name | X width | Y depth | X spacing | Y spacing
 |  |  |  |  |  |  |  |  | Mk2 Heat Bed | 214 | 214 | 210 | 210 | <- Minimum supported size. Do not change
 |  |  |  |  |  |  |  |  | Mk2A 300x300 (https://www.aliexpress.com/item/For-RepRap-3D-Prusa-Mendel-Printer-MK2A-300-300-3-0mm-Heater-Bed-RAMPS-1-4/32668984871.html) | 328 | 328 | 325 | 325
 |  |  |  |  |  |  |  |  | Custom | 300 | 300 | 290 | 290
Min. Build Volume / Travel |  |  |  |  | Build Platform |  | Z Axis
 | X | 300 | mm |  | Mk2A 300x300 | <- Select | Double | <- Select | Build platform mounting bracket data
 | Y | 300 | mm |  | Bed_bracket_15 | <- Select
 | Z | 400 | mm |  | Bracket selection Ok |  |  |  |  | Dimension
 |  |  |  |  |  |  |  |  | Name | offset
 |  |  |  |  | Shafts |  |  |  | Bed_bracket_15 | 15
 |  |  |  | X axis | Diam 10 | <- Select | Thanks to Nicolas Harscoat |  | Bed_bracket_20 | 20
 |  |  |  | Y axis | Diam 10 | <- Select | for the part selector |  | Bed_bracket_25 | 25
 |  |  |  | Z axis | Diam 12 | <- Select |  |  | Bed_bracket_30 | 30
 |  |  |  |  |  |  |  |  | Bed_bracket_45 | 45
 | BOM - Extrusions and linear guides
Item |  | Length | Unit | Qty | Note
3030 Extrusion |  | 420 | mm | 4 | Frame X extrusion
 |  | 410 | mm | 6 | Frame Y extrusion
 |  | 600 | mm | 4 | Frame Z extrusion
2020 Extrusion |  | 415 | mm | 2 | Bed frame X extrusion
 |  | 255 | mm | 2 | Bed frame Y extrusion
Diam 10 | Shaft | 450 | mm | 2 | X axis linear guide
Diam 10 | Shaft | 410 | mm | 2 | Y axis linear guide
Diam 12 | Shaft | 500 | mm | 4 | Z axis linear guide
Diam 8
Diam 10
Diam 12
Single
Double

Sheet: Print List
HyperCube | Printed part quantities
Evolution | All versions | X Axis Versions | Y Axis Versions | Z Axis Versions | Notes
Printed Part Name |  | Diam 10 | Diam 10 | Double
X-Carriage | 1
Belt_Clamp | 2
Belt_Tensioner | 4
Duct | 1
Extruder_Mount | 1
Retainer | 1
T_Slot_Cover | As needed
X_End_Stop_Flag | 2
XY_Idler_Mount_Left |  |  | 1
XY_Idler_Mount_Left_yDia8
XY_Idler_Mount_Right |  |  | 1
XY_Idler_Mount_Right_yDia8
XY_Stepper_Mount Left |  |  | 1
XY_Stepper_Mount Left_yDia8
XY_Stepper_Mount Right |  |  | 1
XY_Stepper_Mount Right_yDia8
Y_Carriage_Clamp_LM8UU
Y_Carriage_Clamp_LM10UU |  |  | 2
Y_Carriage_xDia8_LM8UU
Y_Carriage_xDia8_LM10UU
Y_Carriage_xDia10_LM8UU
Y_Carriage_xDia10_LM10UU |  | 2
Y_End_Stop_Bracket | 2
Y_End_Stop_Flag | 1
Z_Axis_Bearing_Holder |  |  |  | 4
Z_Axis_Linear_Rail_Bracket_-_Left |  |  |  | 2
Z_Axis_Linear_Rail_Bracket_-_Right |  |  |  | 2
Z_Axis_Linear_Rail_Bracket_-_Double_Z_-_Left |  |  |  | 2
Z_Axis_Linear_Rail_Bracket_-_Double_Z_-_Right |  |  |  | 2
Z_Motor_Mount |  |  |  | 2
Z_Nut_Braket |  |  |  | 2

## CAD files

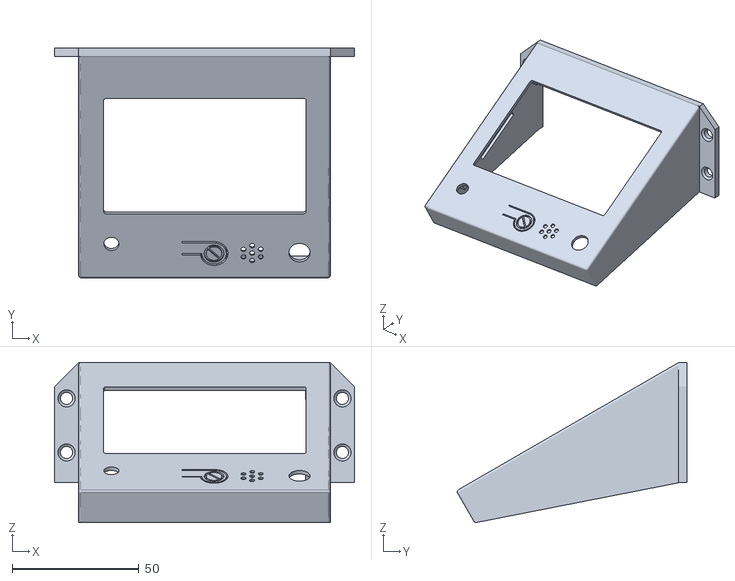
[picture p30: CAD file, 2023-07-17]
Design/STL/RepRap_Full_Graphic_Smart_Controller_Case/RepRap_Full_Graphic_Smart_Controller_Case.stl
118.4 x 90.6 x 63.2

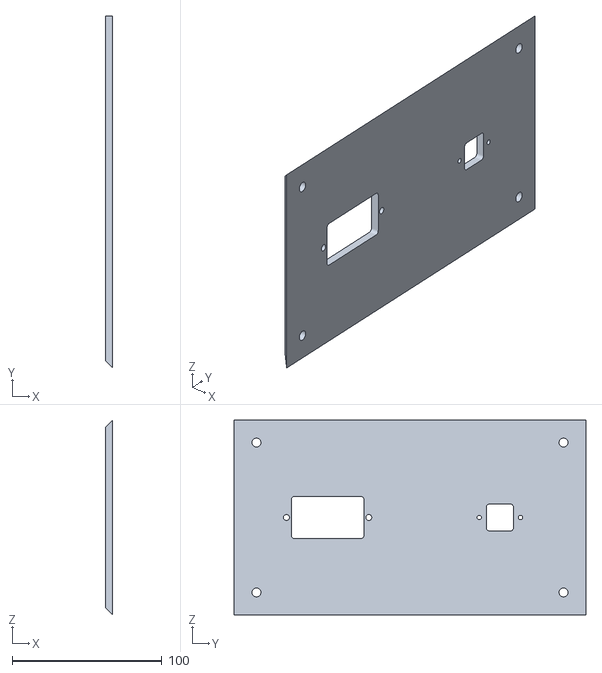
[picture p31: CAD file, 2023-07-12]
Design/STL/Basement Panels/Left Front.stl
5.00 x 235.0 x 130.0

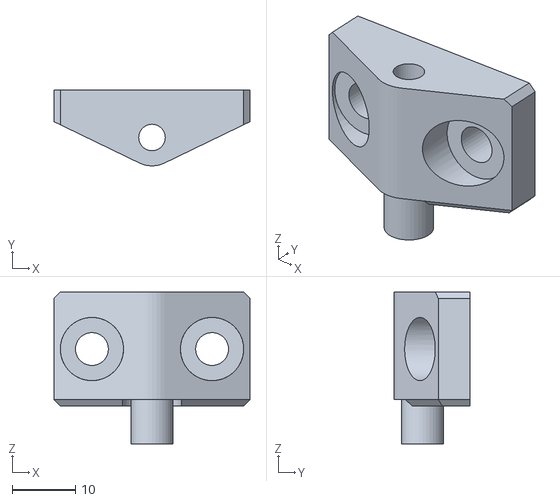
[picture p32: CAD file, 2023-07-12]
Design/STL/Bed Bracket/Bracket_14-9-7.STL
31.0 x 12.0 x 24.0

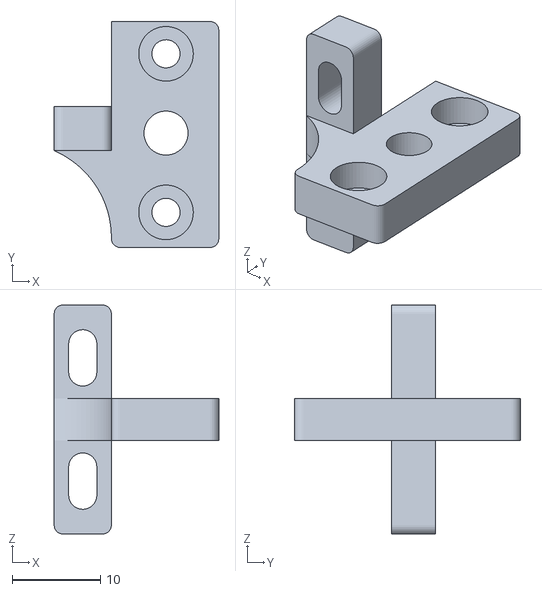
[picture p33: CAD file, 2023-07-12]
Design/STL/BMG/BLtouch Bracket.stl
18.7 x 25.7 x 26.0

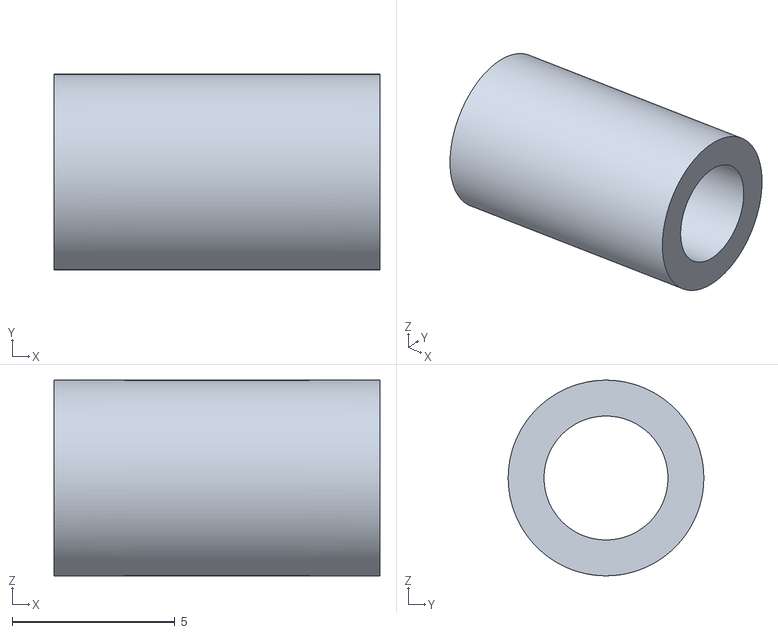
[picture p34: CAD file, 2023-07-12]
Design/STL/Cooling Tunnel For SKR PRO 1.1/Spacer.stl
10.0 x 6.00 x 6.00

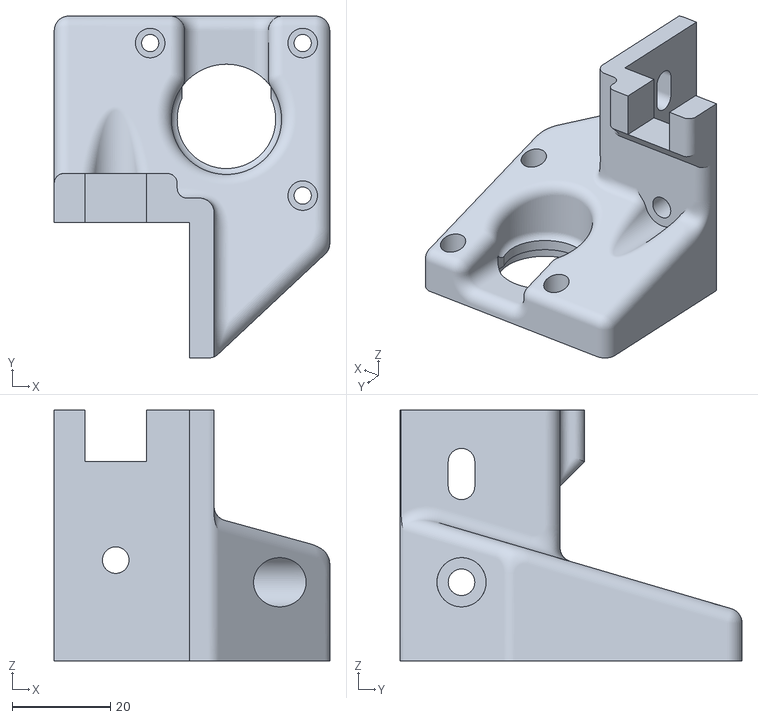
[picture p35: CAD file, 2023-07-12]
Design/STL/Linear Rail/motor-mount-left.stl
56.0 x 69.5 x 51.0

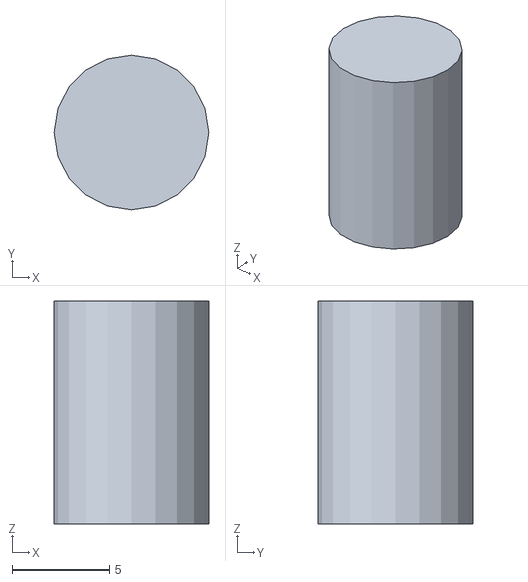
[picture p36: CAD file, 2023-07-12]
Design/STL/Spool/Pin_608zz_Holder.stl
7.97 x 7.97 x 11.5

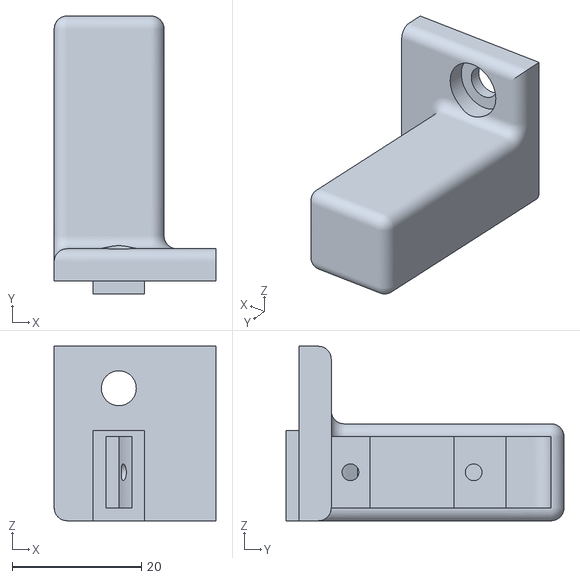
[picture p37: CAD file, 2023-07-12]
Design/STL/Y Axis/3030_Y_End_Stop_Closed.stl
25.0 x 43.0 x 27.0

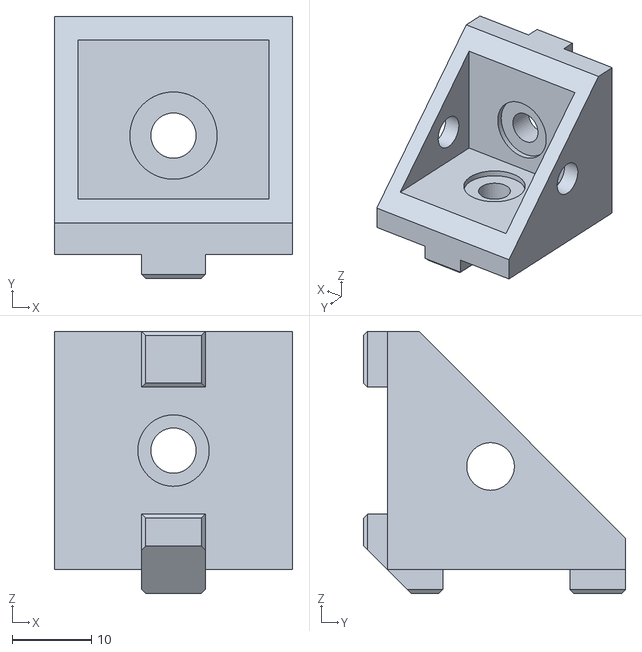
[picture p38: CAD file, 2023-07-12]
Design/STL/Z axis/3030_corner_single.stl
30.0 x 33.0 x 33.0

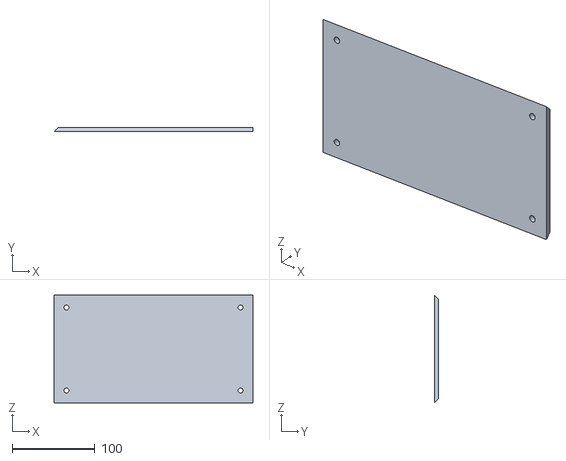
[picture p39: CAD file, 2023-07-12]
Design/STL/Basement Panels/Back Left.stl
240.0 x 5.00 x 130.0

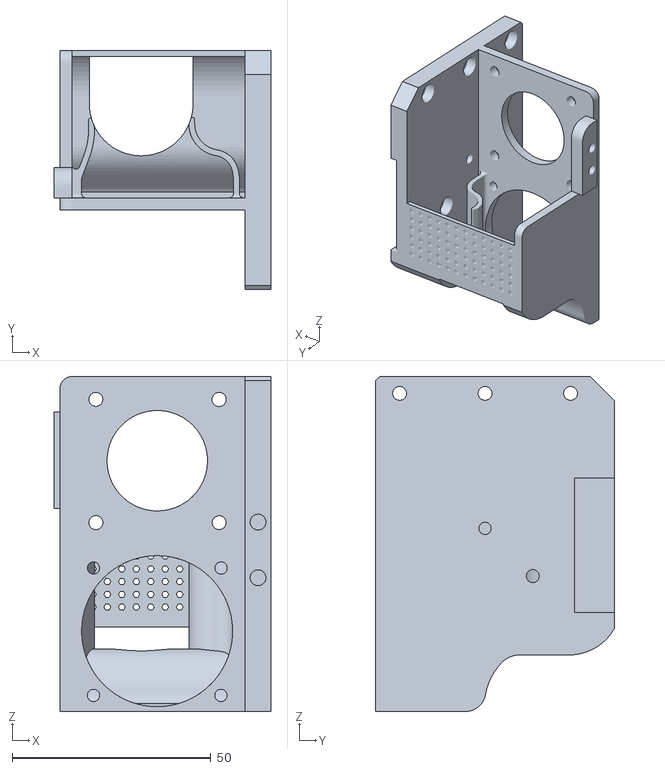
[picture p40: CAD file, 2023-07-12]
Design/STL/BMG/BMG Bracket.stl
54.6 x 60.0 x 84.3

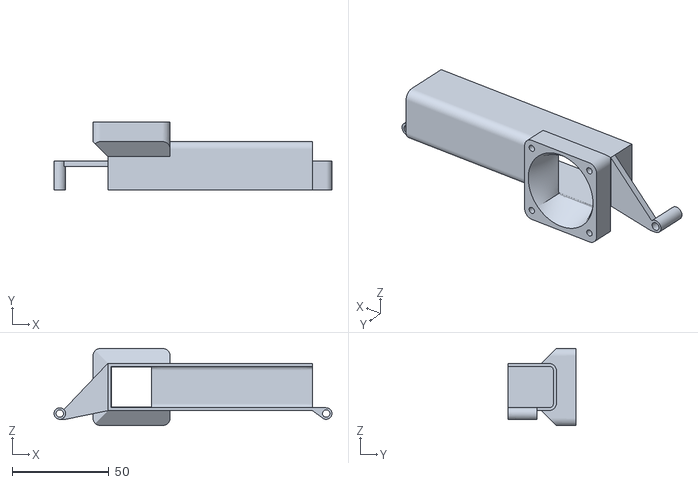
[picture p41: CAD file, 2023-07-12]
Design/STL/Cooling Tunnel For SKR PRO 1.1/cooling_tunnel_v2.stl
144.0 x 35.0 x 40.0

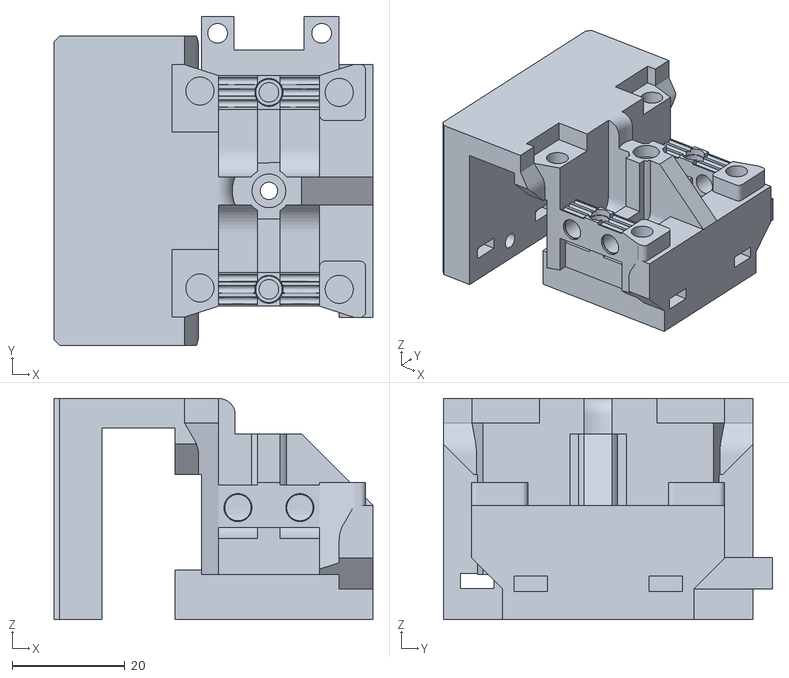
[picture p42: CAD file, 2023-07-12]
Design/STL/Linear Rail/Extruder_RailMount.stl
56.7 x 58.5 x 39.3

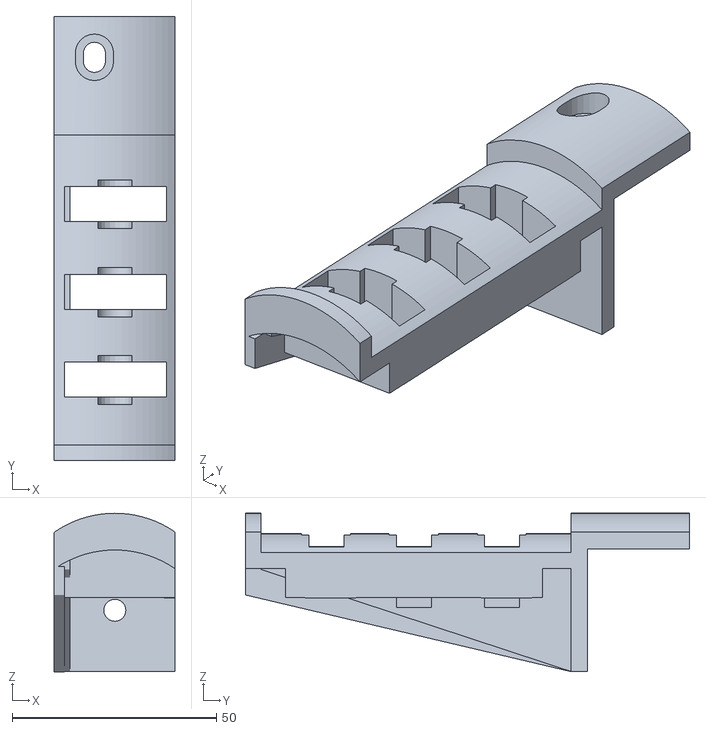
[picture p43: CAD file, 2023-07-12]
Design/STL/Spool/Spool_Mount_3_x_608zz.stl
29.6 x 108.8 x 38.8

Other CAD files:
Design/STL/Basement Panels/Front Right.stl
Design/STL/Linear Rail/YFlag.stl
Design/STL/Z axis/Z_Axis_Linear_Rail_Bracket_-_Double_Z_-_Left_1.1.stl
Design/STL/Basement Panels/Right Front.stl
Design/STL/Basement Panels/Back Right.stl
Design/STL/Basement Panels/Front Left.stl
Design/STL/Basement Panels/Left Back.stl
Design/STL/Basement Panels/Right Back.stl
Design/STL/Linear Rail/BeltClamp_v1.stl
Design/STL/Linear Rail/Belt_Tensioner_1.0.stl
Design/STL/Linear Rail/Extruder_Cables_Support.stl
Design/STL/Linear Rail/Intersect_Left.stl
Design/STL/Linear Rail/Intersect_Right.stl
Design/STL/Linear Rail/XFlag.stl
Design/STL/Linear Rail/XY_Idler_Mount.stl
Design/STL/Linear Rail/motor-mount-right.stl
Design/STL/Z axis/3030_Cable_Tie_Down_v6.stl
Design/STL/Z axis/Z_Axis_Bearing_Holder_1.0.stl
Design/STL/Z axis/Z_Axis_Linear_Rail_Bracket_-_Double_Z_-_Right_1.1.stl
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
